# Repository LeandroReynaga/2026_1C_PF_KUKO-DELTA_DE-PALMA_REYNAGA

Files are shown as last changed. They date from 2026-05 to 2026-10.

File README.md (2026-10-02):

<div align="center">
Banner_KUKO_Delta_Carbon
<br>

# KUKO DELTA CARBON

### Robot delta de 3 GDL con visión artificial para clasificación de piezas sobre cinta en movimiento

<br>













<br>

Universidad Nacional de Lomas de Zamora — Facultad de Ingeniería

**Universidad Nacional de Lomas de Zamora · Facultad de Ingeniería**<br>
**Ingeniería Mecatrónica**

</div>

---

## Ficha del proyecto

| | |
| :--- | :--- |
| **Proyecto** | KUKO Delta Carbon |
| **Tipo** | Proyecto Final (PF) |
| **Año / Período** | 2026 — 1.er Cuatrimestre |
| **Carrera** | Ingeniería Mecatrónica |
| **Autores** | **DE PALMA, Marcos Agustín** · **REYNAGA RÍOS, Leandro Joel**  |
| **Institución** | Facultad de Ingeniería — UNLZ |
| **Estado** | 🟢 Prototipo funcional |
| **Repositorio** | `2026_1C_PF_KUKO-DELTA_DE-PALMA_REYNAGA` |

---

<p align="center">
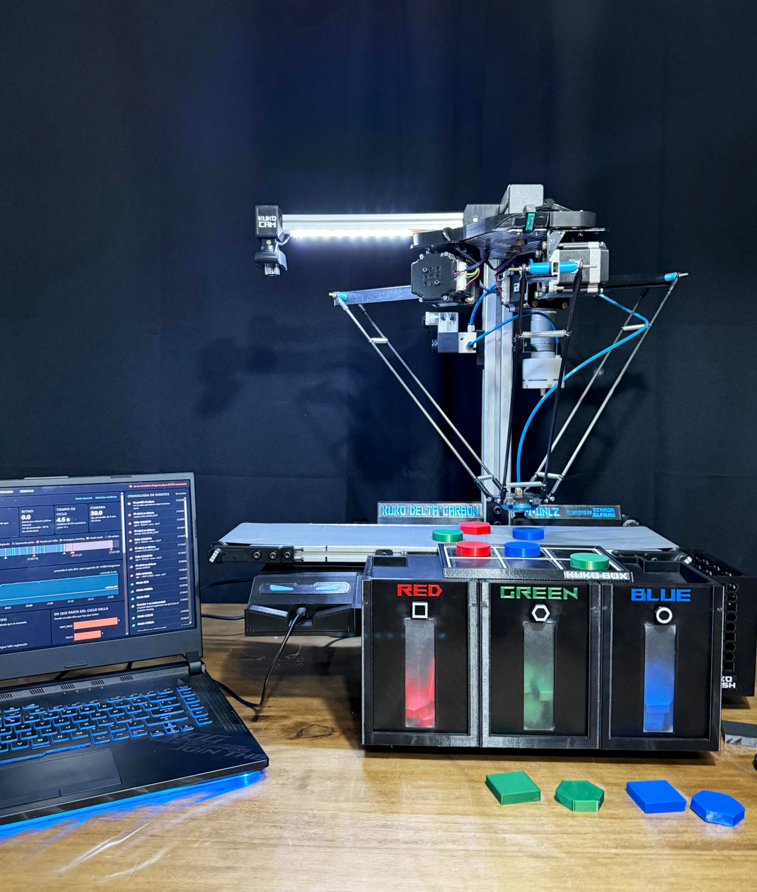
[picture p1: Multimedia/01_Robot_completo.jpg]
KUKO Delta Carbon
  
  <br>
  <em>Imagen 1: KUKO Delta Carbon</em>
</p>

---

## 📑 Índice

|  #  | Sección | Contenido |
| :-: | :--- | :--- |
|  1  | [Introducción y objetivos](#introduccion) | Contexto, problema y objetivos |
|  2  | [Brief](#brief) | Pitch, solución, alcance y estado |
|  3  | [Multimedia](#multimedia) | GIF, videos y visor 3D con AR |
|  4  | [Descripción técnica](#descripcion-tecnica) | Cómo funciona por dentro |
|  5  | [Instrucciones de uso](#uso) | Puesta en marcha reproducible |
|  6  | [Desarrollo del proyecto](#desarrollo) | Diagrama de Gantt |
|  7  | [Autores](#autores) | Contacto |

---

## 1 · Introducción y objetivos

### Contexto

**KUKO Delta Carbon** es una celda de clasificación, de escala didáctica pero con criterios
industriales, construida íntegramente por los autores: mecánica, electrónica, firmware, visión
artificial e interfaz de operación.

### Problema a resolver

Tomar piezas **en movimiento** sobre una cinta transportadora y depositarlas en el destino que les
corresponde, sin detener la cinta, es un problema de sincronización. Resolverlo exige medir la latencia del sistema
de visión, predecir la posición futura de la pieza y planificar la intercepción, todo con hardware
de bajo costo y sobre motores paso a paso.

### Objetivo general

> Diseñar, construir y poner en marcha una celda robótica de clasificación automática basada en un
> robot delta de 3 grados de libertad, capaz de detectar piezas por **color** y **forma** mediante
> visión artificial, interceptarlas sobre una cinta en movimiento y depositarlas en su destino,
> supervisada desde una interfaz de operación propia.

---

## 2 · Brief

> **KUKO Delta Carbon** es una celda robótica *pick & place* que clasifica piezas por color y forma
> sobre una cinta en movimiento, pensada para tareas de selección repetitivas.

Este proyecto **KUKO Delta Carbon** (Proyecto Final, **2026 · 1.er Cuatrimestre**) resuelve la
**clasificación manual de piezas en línea de producción** mediante un **robot delta de 3 GDL con
visión artificial que intercepta las piezas sin detener la cinta**.
Permite **clasificar
por color, por forma o armar una caja de 6 posiciones**, con una interfaz que muestra en vivo el
estado de cada componente, la producción acumulada y la disponibilidad de la celda.

Se implementa con **ESP32 + C++ (PlatformIO)** para el control en tiempo real y **Python + OpenCV +
NiceGUI** para la visión y la operación, y se valida con **98 pruebas automáticas** que verifican
tanto el protocolo de comunicación como la matemática del movimiento.

<table>
<tr><td width="52%" valign="top">

**Para lograrlo:**

- 👁️ **Detecta** piezas por color (rojo · verde · azul) y forma (cuadrado · hexágono · círculo)
- 🎯 **Intercepta** la pieza en movimiento
- 🗑️ **Clasifica** en 3 tachos, por color o por forma
- 📦 **Modo Box:** llena una caja de 6 celdas con una disposición de colores configurable
- 🛡️ **Supervisa colisiones** con encoders magnéticos y se recupera sola rehomeando
- 🧑‍🏫 **Modo Teach:** el operador mueve el brazo a mano, graba secuencias y las reproduce
- 📊 **Mide su propia producción:** piezas, ritmo, fallos y disponibilidad
- ⚙️ **62 parámetros ajustables**, sin recompilar y persistidos en la placa

</td><td width="48%" valign="top">

```
      Cámara USB 720p
             ↓  OpenCV (HSV + contornos)
  Color · Forma · Posición Y
             ↓  Serie 115200 8N1
  ESP32 — planificación e intercepción
             ↓  Cinemática inversa delta
  3 × NEMA 23 (10.000 µpasos/vuelta)
             ↓  Ventosa de vacío
  Pieza depositada en su destino
             ↑
  3 × AS5600 → supervisión de colisión
```

</td></tr>
</table>

### Alcance

<table>
<tr>
<th width="50%">✅ Incluye</th>
<th width="50%">🚫 No incluye</th>
</tr>
<tr><td valign="top">

- Robot delta de 3 GDL con ventosa de vacío
- Cinta transportadora con velocidad regulada por PWM
- Visión artificial por color y forma, con seguimiento
- Intercepción de piezas en movimiento
- Detección de colisiones y recuperación automática
- Registro de fallos e indicadores de producción
- Interfaz web de operación, proceso y servicio
- Modo Teach con grabación y reproducción de rutas
- Movimiento lineal (movL) en el espacio cartesiano

</td><td valign="top">

- Alimentador automático de piezas
- Vacuostato (confirmación física del vacío)
- Vision Artificial con Redes neuronales

</td></tr>
</table>

### Estado del proyecto

| Aspecto | Estado |
| :--- | :--- |
| **Madurez** | ✅ Prototipo funcional |
| **Ciclo completo** | ✅ Homing → detección → intercepción → agarre → clasificación → retorno |
| **Modos operativos** | ✅ Color · Forma · Box · Teach |
| **Seguridad** | ✅ Supervisión de colisión activa, con recuperación automática |
| **Interfaz** | ✅ 6 pestañas operativas (Operación, Teach, Rendimiento, Visión, Proceso, Servicio) |

---

## 3 · Multimedia

<p align="center">
  <a href="https://leandroreynaga.github.io/2026_1C_PF_KUKO-DELTA_DE-PALMA_REYNAGA/Multimedia/KUKO_AR/">
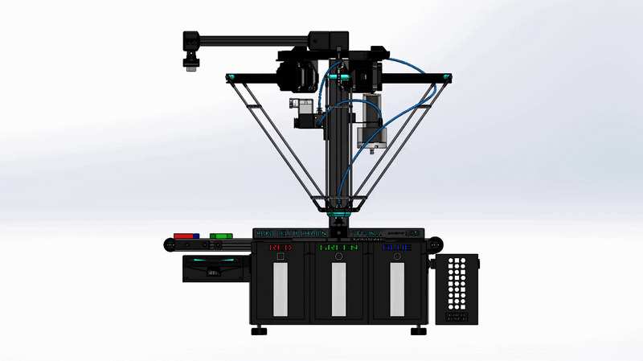
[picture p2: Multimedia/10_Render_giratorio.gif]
Render giratorio: clic para ver el robot en 3D y realidad aumentada
    
  </a>
  <br>
  <em>Figura 1: Render giratorio del modelo 3D</em>
</p>

<p align="center">
  <a href="https://leandroreynaga.github.io/2026_1C_PF_KUKO-DELTA_DE-PALMA_REYNAGA/Multimedia/KUKO_AR/"><b>🔍 Ver en 3D y Realidad Aumentada</b></a>
</p>
<p align="center">
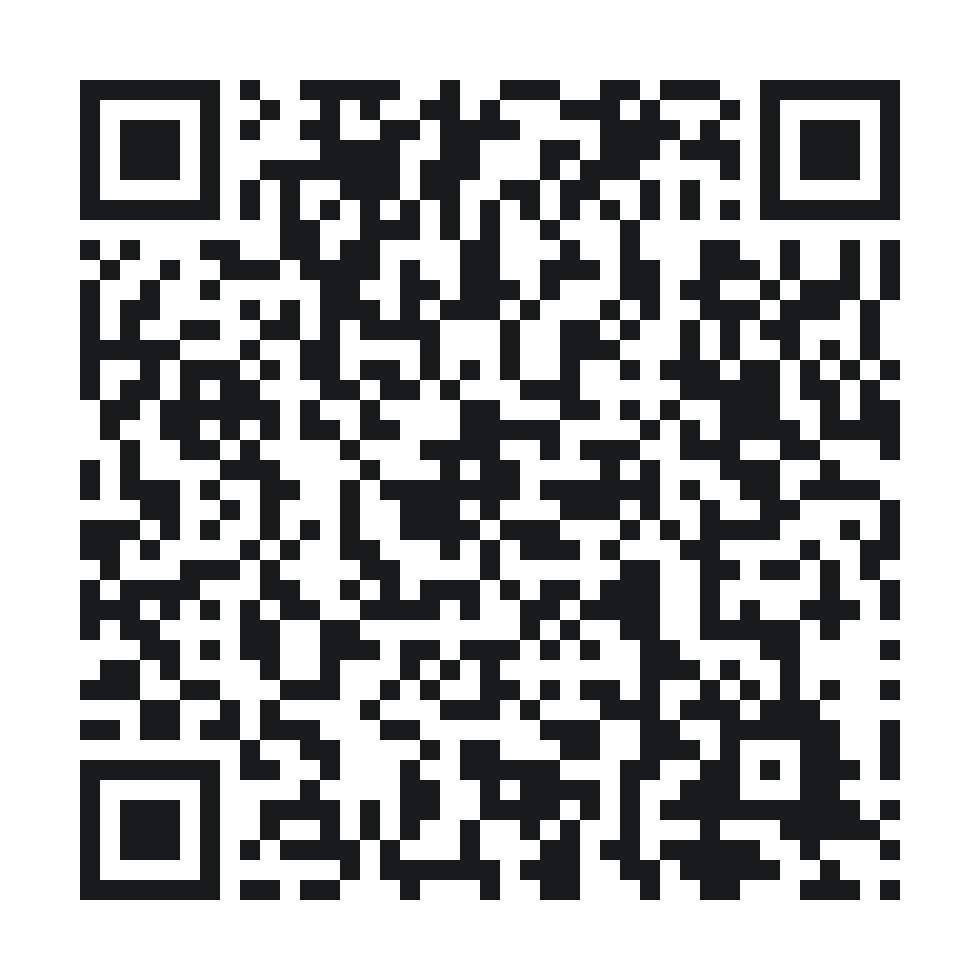
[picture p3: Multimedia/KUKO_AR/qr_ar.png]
Código QR para ver el robot en realidad aumentada
  
  <br>
  <em>Enlace 1: Haz clic en el render o escanea el QR con el celular para ver el robot en 3D y en realidad aumentada.</em>
</p>

<p align="center">
  Clasificación por color
  <br>
  <em>Figura 2: Clasificación por color</em>
</p>

<p align="center">
  Clasificación por forma
  <br>
  <em>Figura 3: Clasificación por forma</em>
</p>

<p align="center">
  Modo Box
  <br>
  <em>Figura 4: Modo Box</em>
</p>

<p align="center">
  Modo Teach
  <br>
  <em>Figura 5: Modo Teach</em>
</p>

<p align="center">
  <a href="https://youtube.com/playlist?list=PLV_DUMoOxinw&amp;si=bVj7ZXU2DtyZ1oJc">
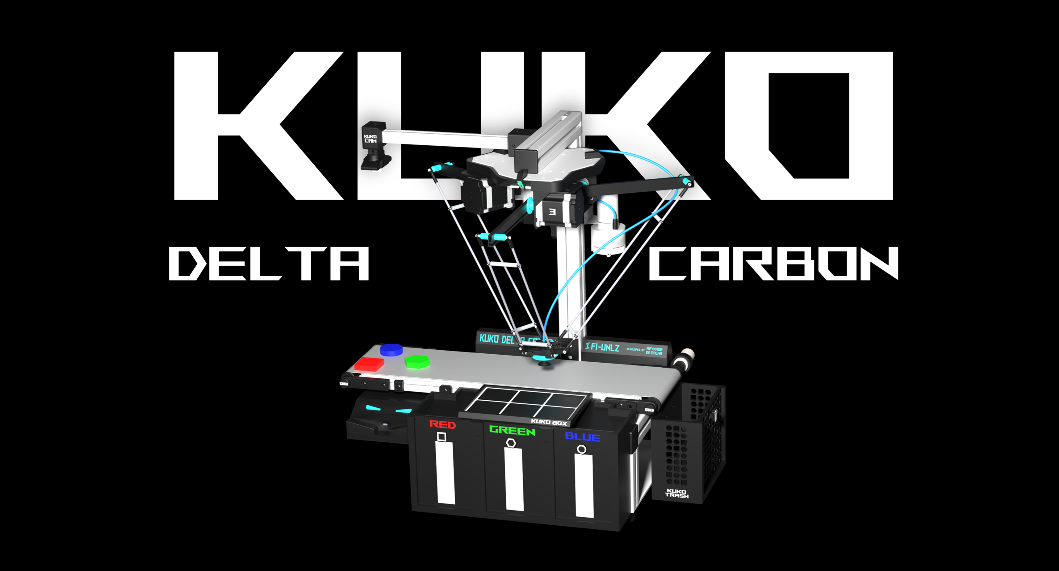
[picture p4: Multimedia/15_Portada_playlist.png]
Playlist de videos del KUKO Delta Carbon
    
  </a>
</p>
<p align="center">
  <em>Enlace 2: Haz clic en la imagen para ver la playlist con los videos de los modos.</em>
</p>

<p align="center">
  <a href="https://drive.google.com/drive/folders/15TBgdvEbJJ4iwdDsnXzpPRDG5-t90HLm?usp=drive_link">
    Google Drive_Logo

  </a>
</p>
<p align="center">
  <em>Enlace 3: Haz clic en la imagen para descargar el modelo 3D y los videos.</em>
</p>

---

## 4 · Descripción técnica

El sistema se reparte responsabilidades: el ESP32 hace
lo que **no puede esperar** (generar pasos, leer encoders, decidir cuándo bajar el brazo) y la PC hace
lo que **necesita memoria y potencia** (procesar imagen, dibujar, recordar sucesos).

### 4.1 · Ciclo de clasificación

```mermaid
stateDiagram-v2
    direction LR
    [*] --> HOMING
    HOMING --> WAIT_PIECE : finales de carrera + calibración de encoders
    WAIT_PIECE --> PICK_APPROACH : llega una pieza alcanzable
    PICK_APPROACH --> PICK_DESCEND : espera sobre el punto de encuentro
    PICK_DESCEND --> PICK_LIFT : baja a favor de la cinta y toma la pieza
    PICK_LIFT --> GO_BIN : modo Color / Forma
    PICK_LIFT --> BOX_TRANSIT : modo Box
    GO_BIN --> BIN_SETTLE
    BIN_SETTLE --> RELEASE_WAIT
    RELEASE_WAIT --> WAIT_PIECE
    BOX_TRANSIT --> BOX_APPROACH
    BOX_APPROACH --> BOX_DESCEND
    BOX_DESCEND --> BOX_LIFT
    BOX_LIFT --> WAIT_PIECE
    WAIT_PIECE --> GO_HOME_IDLE : sin piezas en cola
    GO_HOME_IDLE --> WAIT_PIECE
    HOMING --> COLLISION_STOP : cualquier estado puede caer acá
    COLLISION_STOP --> HOMING : recalibra conservando la cola
    WAIT_PIECE --> TEACH : pedido del operador (J1)
    TEACH --> WAIT_PIECE
```

<p align="center"><em>Figura 6: Máquina de estados del ciclo de clasificación</em></p>

### 4.2 · Modos de clasificación

| Modo | Comando | Qué hace |
| :--- | :-----: | :--- |
| **Color** | `C` | Tacho 1 rojo · Tacho 2 verde · Tacho 3 azul |
| **Forma** | `F` | Tacho 1 cuadrado · Tacho 2 hexágono · Tacho 3 círculo |
| **Box** | `A` | Llena una caja de 6 celdas (2 filas × 3 columnas) con una disposición de colores configurable; máximo 3 piezas por color. El resto de las piezas siguen de largo |

### 4.3 · Visión artificial

La detección corre en la PC sobre **OpenCV**, con procesamiento clásico (sin redes neuronales): es
determinístico, se calibra a mano.

**La `X` de la pieza no viaja por el enlace.** Como el aviso se emite exactamente en el cruce de la
 línea de detección, la `X` es siempre la misma y es conocida por las dos partes. Solo viajan
 `Y`, color y forma — tres campos, dos comas, una línea.

### 4.4 · Cinemática

`DeltaKinematics` es un espacio de nombres puramente matemático —sin entrada/salida ni llamadas a
motores— que resuelve la **cinemática inversa** del delta. La **cinemática directa** vive del lado de
Python (`cinematica.py`), y la necesita para dibujar el brazo en pantalla.

### 4.5 · Generación de pasos y perfiles de movimiento

Cada eje se maneja con un **timer de hardware dedicado** del ESP32 y una rampa trapezoidal calculada
con el **algoritmo de Austin (2004)**.

**Coordinación multi-eje.** `Motors::moveSynchronized` escala velocidad y aceleración de cada eje en
proporción a su recorrido, de modo que los tres motores **arrancan y llegan juntos** aunque recorran
distancias distintas.

### 4.6 · Supervisión de colisiones

**No es control de posición** — la posición sigue siendo lazo abierto por micropasos. Es un
 **detector de discrepancia**: en cada vuelta del loop compara el ángulo medido contra el que dicen
 los pasos emitidos, y si la diferencia supera el umbral **y se sostiene** durante un tiempo de
 confirmación, declara colisión.

**El umbral no es fijo:**

```
umbral_efectivo = UMBRAL_DEG + MARGEN_VELOCIDAD_MS × velocidad
```

**Reacción ante colisión:** frena los 3 ejes → suelta la pieza → espera 3 s → rehomea conservando la
cola de piezas. Tras 3 colisiones seguidas, pasa a `ERROR`.

### 4.7 · Modo Teach

Un modo aparte del ciclo de clasificación: el operador maneja el brazo a mano desde la interfaz, graba
secuencias y las reproduce. Incluye verificación por etapas.

### 4.8 · Interfaz de operación

Aplicación web local hecha con **NiceGUI**, en un solo proceso y tres hilos: visión, enlace serie y
servidor web. Sirve para controlar el proceso, modificar variables, enterarse de errores y verificar componentes. 

---

## 5 · Instrucciones de uso

### 5.1 · Requisitos previos

| Categoría | Requisito |
| :--- | :--- |
| **Sistema operativo** | Windows 10/11  |
| **Firmware** | [PlatformIO](https://platformio.org/) (CLI `pio` o la extensión de VS Code) |
| **PC** | Python **3.13** o superior |
| **Driver USB** | CP2102 — incluido en [`Código/Driver_USB_CP2102/`](C%C3%B3digo/Driver_USB_CP2102/) |
| **Hardware** | Robot Kuko Delta Carbon |

### 5.2 · Instalación

**a) Clonar el repositorio**

```bash
git clone https://github.com/<usuario>/2026_1C_PF_KUKO-DELTA_DE-PALMA_REYNAGA.git
cd "2026_1C_PF_KUKO-DELTA_DE-PALMA_REYNAGA/Código/KUKO_DELTA_CARBON"
```

**b) Instalar el driver USB** (solo la primera vez)

Ejecutar el instalador de `Código/Driver_USB_CP2102/CP210x_Universal_Windows_Driver/` según la
arquitectura de la PC. Sin esto, el ESP32 no aparece como puerto COM.

**c) Compilar y cargar el firmware**

```bash
pio run                        # compila el entorno "main"
pio run -e main -t upload      # flashea la placa
pio device monitor             # monitor serie a 115200 baudios
```

<details>
<summary><b>Entornos de compilación disponibles</b></summary>

<br>

La carpeta `pruebas/` guarda sketches históricos (`.bak`) de motores, encoders y cinemática, además de
`test.cpp`, que es lo que compila el entorno `test`. Los `.bak` no forman parte de ningún build, pero
sirven de referencia al depurar un subsistema por separado.

</details>

**d) Preparar la aplicación de PC**

```bash
python -m venv pc/.venv
pc\.venv\Scripts\pip install -r pc/requirements.txt
```

### 5.3 · Puesta en marcha

```bash
pc\.venv\Scripts\python pc/kuko_app.py
```

Opciones útiles:

```bash
pc\.venv\Scripts\python pc/kuko_app.py --puerto COM5      # forzar el puerto serie
pc\.venv\Scripts\python pc/kuko_app.py --sin-vision       # trabajar en la interfaz sin cámara
pc\.venv\Scripts\python pc/kuko_app.py --sin-navegador    # no abrir el navegador solo
```

La interfaz queda en **`http://localhost:8080`**.

---

## 6 · Desarrollo del proyecto

El proyecto se construyó **de abajo hacia arriba**: primero cada subsistema por separado y verificado
en aislamiento, después la integración. Cada capa nueva se apoyó en una que ya estaba medida.

### Diagrama de Gantt

Cronograma del proyecto de marzo a octubre de 2026, en seis etapas. El detalle de cada tarea está en el
[Diagrama de Gantt final](Documentaci%C3%B3n/Diagrama%20de%20Gantt/Diagrama_de_Gantt_final.pdf).

<p align="center">
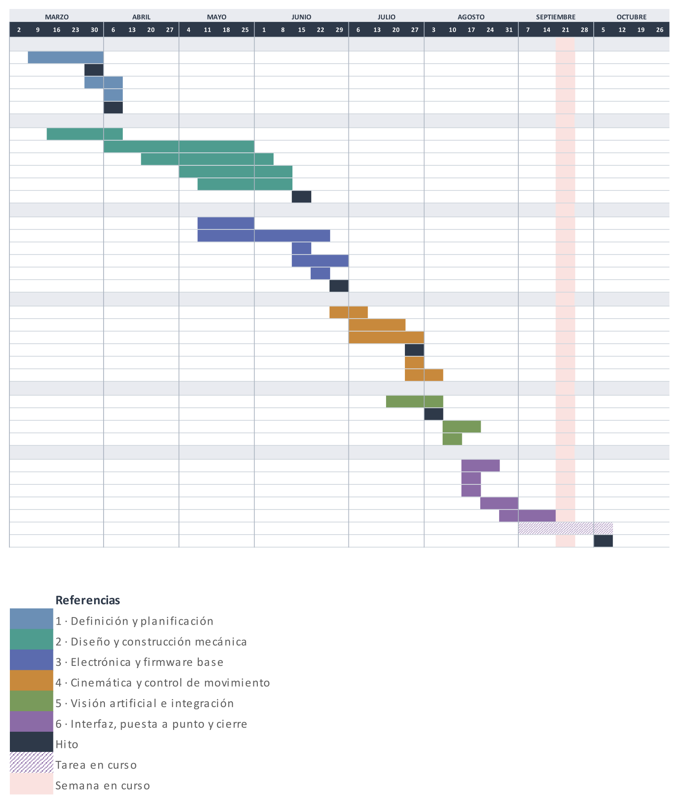
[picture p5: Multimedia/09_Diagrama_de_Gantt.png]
Diagrama de Gantt final
  
  <br>
  <em>Figura 7: Diagrama de Gantt final</em>
</p>

---

## 7 · Autores

<table align="center">
<tr><td width="50%" align="center">

### DE PALMA<br>Marcos Agustín

Ingeniería Mecatrónica — FI-UNLZ

📧 <marcosdepalma03@gmail.com>

💻 GitHub [@MarcosDePalma](https://github.com/MarcosDePalma)

</td><td width="50%" align="center">

### REYNAGA RÍOS<br>Leandro Joel

Ingeniería Mecatrónica — FI-UNLZ

📧 <leandro_05_01@hotmail.com>

💻 GitHub [@LeandroReynaga](https://github.com/LeandroReynaga)

</td></tr>
</table>

---

<div align="center">

**KUKO DELTA CARBON**

**Facultad de Ingeniería — Universidad Nacional de Lomas de Zamora**<br>
Proyecto Final · 2026 · 1.er Cuatrimestre

</div>

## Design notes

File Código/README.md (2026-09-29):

# Código

Código fuente del **KUKO Delta Carbon** y el driver USB para conectar la placa a la PC.

El sistema son dos partes que se comunican por puerto serie: el **firmware** del ESP32
(PlatformIO / Arduino) y la **aplicación de PC** (Python).

## Contenido

| Carpeta | Contenido |
|---|---|
| [`KUKO_DELTA_CARBON/`](KUKO_DELTA_CARBON/) | Proyecto completo: firmware y aplicación de PC. |
| [`Driver_USB_CP2102/`](Driver_USB_CP2102/) | Driver de Windows para el conversor USB-serie CP2102 de la NodeMCU-32S, comprimido y descomprimido. |

## KUKO_DELTA_CARBON

| Ubicación | Contenido |
|---|---|
| `platformio.ini` | Configuración de PlatformIO: entorno `main` (firmware) y `test` (pruebas de placa). |
| `include/Pinout.h` | Asignación de pines del ESP32. Es el único lugar donde se definen. |
| `src/` | Firmware: máquina de estados, generación de pasos, cinemática, trayectorias, encoders, finales de carrera, neumática y cinta. |
| `pc/` | Aplicación de PC: enlace serie, visión, interfaz, teach y rendimiento. |
| `pc/PROTOCOLO.md` | Protocolo de comunicación serie entre la PC y el ESP32. |
| `pc/tests/` | Pruebas de la aplicación de PC. |
| `vision_python/` | Módulos de visión calibrados: cámara, detección por color y forma, seguimiento y conversión a coordenadas del robot. |
| `pruebas/` | Programas de prueba de la puesta en marcha de la placa. |
| `estructura.txt` | Estructura del proyecto, archivo por archivo. |
| `CLAUDE.md` | Guía del proyecto para Claude Code. |

**Volumen:** ~11.400 líneas de firmware (C++) y ~19.600 de aplicación de PC (Python).

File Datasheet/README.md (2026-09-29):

# Datasheets

Hojas de datos de los componentes principales del KUKO Delta Carbon.

| Componente | Archivo | Dato que interesa |
| :--- | :--- | :--- |
| ESP32 NodeMCU-32S | `esp32_nodemcu_32s.pdf` | Pines con ADC, canales PWM, timers de hardware |
| Driver DM556 | `dm556.pdf` | Tabla de microstepping y de corriente (DIP switches) |
| Motor NEMA 23 | `nema23.pdf` | Par, corriente por fase, inercia del rotor |
| Encoder AS5600 | `as5600.pdf` | Salida analógica, resolución, alimentación ratiométrica |
| Bomba de vacío | `microbomba.pdf` | Consumo y caudal |
| Electroválvula | `electrovalvula.pdf` | Alimentación, acción directa, rango de presiones|
| Cámara USB | `camara_usb.pdf` | Resolución, modos de captura |
| Driver DRV8833 | `drv8833.pdf` | Pinout, corriente máxima |
| Motorreductor 60RPM | `motorreductor.pdf` | Torque a tensión nominal, rpm |
| Switch Final de Carrera | `final_de_carrera.pdf` | Dimensiones, NO y NC|

---

> **Los aspectos más importantes**

> - La **placa ESP32** debe tener suficiente capacidad de procesamiento y cantidad de pines para todos los componentes del robot.
> - La selección del modelo de **motores paso a paso** es fundamental para garantizar **torque sostenido a altas RPM** ya que una caída
>   del torque genera pérdida de pasos.
> - El **circuito neumático** debe ser capaz de generar vacío y liberar el sistema **a alta velocidad**.
> - La **cámara** debe tener suficiente resolución y contraste.
> - La **cinta transportadora** no debe trabarse durante el funcionamiento.

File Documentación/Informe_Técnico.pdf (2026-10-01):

### Universidad Nacional de Lomas de Zamora

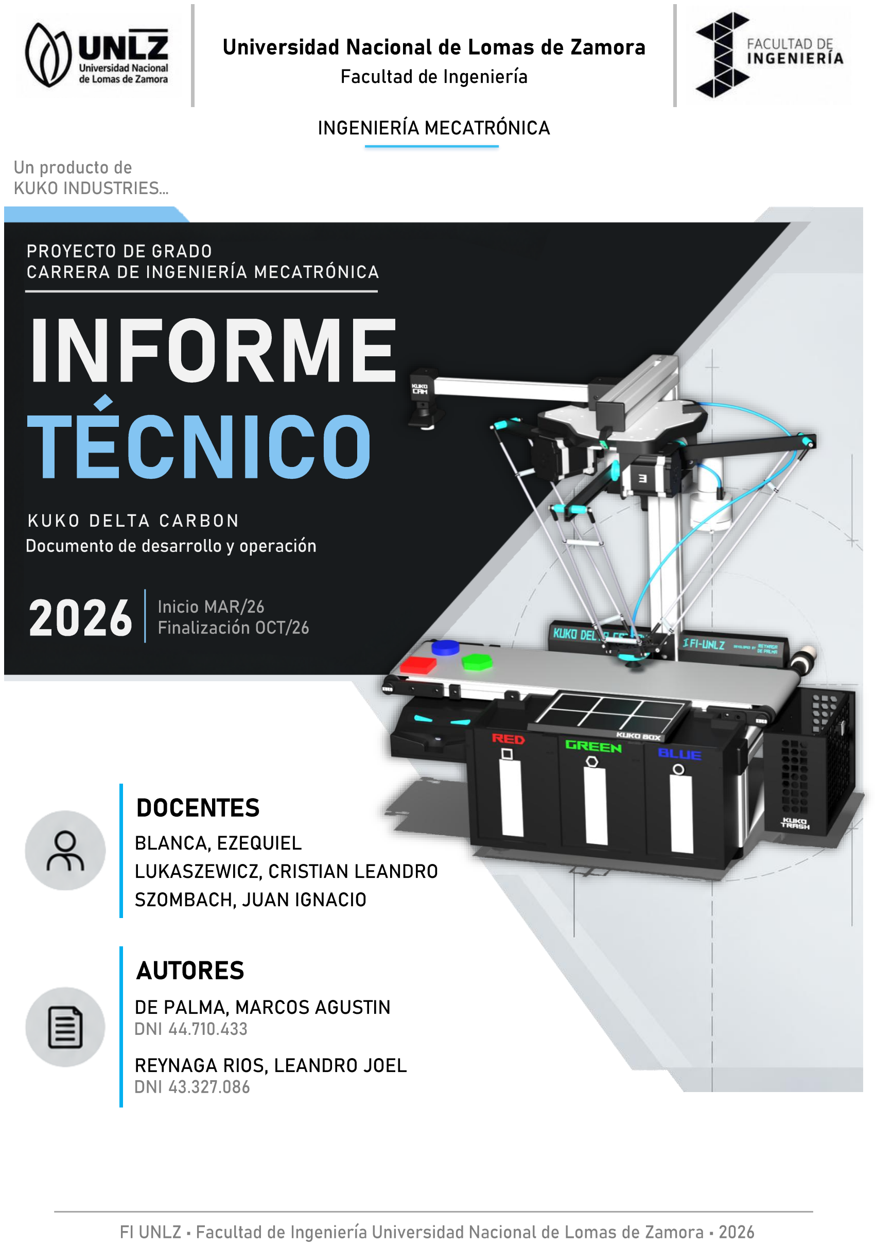
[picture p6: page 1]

Facultad de Ingeniería

INGENIERÍA MECATR ÓNICA

Un producto de
KUKO INDUSTRIES …

z

## DOCENTES

BLANCA, EZEQUIEL
LUKASZEWICZ, CRISTIAN LEANDRO SZOMBACH, JUAN IGNACIO

## AUTORES

DE PALMA, MARCOS AGUSTIN
DNI 44.710.433

REYNAGA RIOS, LEANDRO JOEL DNI 43.327.086

PROYECTO DE | GRADO
CARRERA DE | INGENIERÍA MECATRÓNICA

# INFORME TÉCNICO

KUKO DELTA CARBON
Documento de desarrollo y operación

2026 Inicio MAR/26
Finalización OCT/26

FI UNLZ • Facultad de Ingeniería Universidad Nacional de Lomas de Zamora • 2026

Índice

## Índice

Índice

Índice

11.1. Arquitectura de la aplicación | 61
11.2. Pestaña de Operación | 61
11.3. Pestaña de Teach | 62
11.4. Pestaña de Rendimiento | 63
11.5. Pestaña de Visión | 65
11.6. Pestañas de Proceso y Servicio | 66
12. | PLANIFICACIÓN Y DESARROLLO | | 69
12.1 Diagrama de Gantt inicial | 69
12.2 Diagrama de Gantt final | 69
12.2 Aclaración | 71
12.3 Comparativa | 72
13. | PRUEBAS Y RESULTADOS | | 73
13.1 Pruebas durante el desarrollo | 73
13.2 Resultados de funcionamiento | 73
14. | ANÁLISIS ECONÓMICO | | 74
14.1. Criterios de selección de proveedores | 74
14.2. Listado de materiales y costos | 75
14.3. Desvío presupuestario | 76
15. | CONCLUSIONES | | 77
15.1 Conclusiones generales | 77
15.2. Mejoras futuras | 78
16. | MATERIAL GRÁFICO Y AUDIOVISUAL | | 79
Recorrido del proyecto | 79
Playlist: Videos de los modos | 80
Video modo: Clasificación por color | 80
Video modo: Clasificación por forma | 80
Video modo: Box | 80
Video modo: Teach | 81
Autores del proyecto | 81

Introducción

## 1. INTRODUCCIÓN

### 1.1. Contexto y motivación

Siguiendo la línea de desarrollo del robot KUKO S -300 realizado en la materia Robótica, nos vimos impulsados a crear el KUKO Delta Carbon , un modelo con aplicación industrial. Buscamos crear un sistema de clasificación Pick and Place, compuesto por un robot delta, una cinta transportadora y depósitos fijos, destinado al manejo de piezas livianas en entornos productivos.

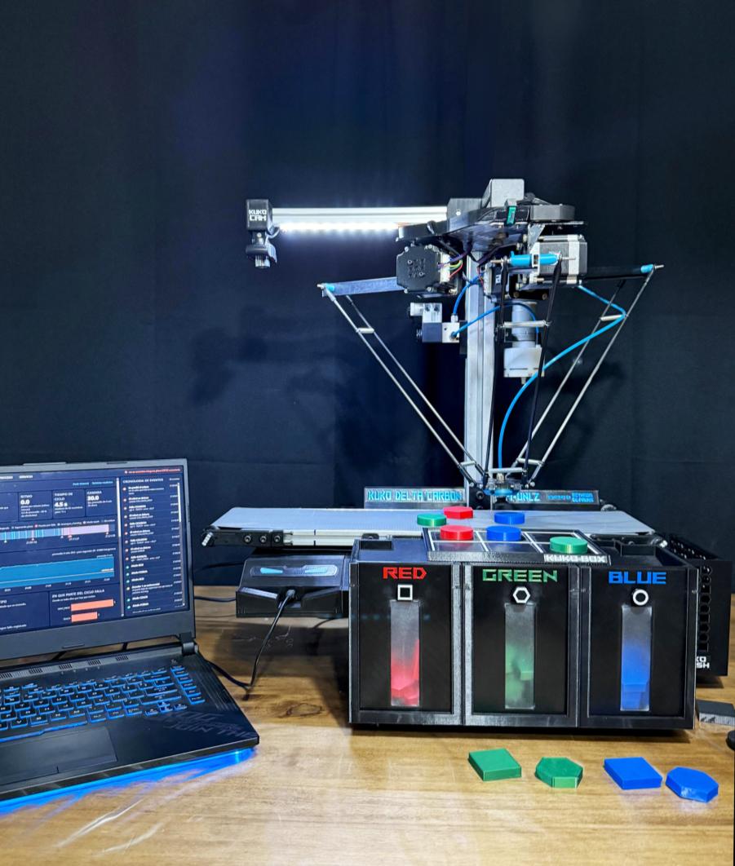
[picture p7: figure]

Imagen 1 – Kuko Delta Carbon

Inicialmente, se planteó el desarrollo de un robot de configuración SCARA de 3 grados de libertad con gripper mecánico, aprovechando el conocimiento adquirido con el S -300, un robot de 2 grados de libertad . Sin embargo, al analizar los requerimientos de velocidad y productividad del sistema, se concluyó que dicha configuración no resultaba adecuada para cumplir con las exigencias planteadas.

En búsqueda de velocidad y precisión, los robots paralelos del tipo DELTA destacan por sobre el resto, y esto nos motivó a optar por esta configuración. Este tipo de robot es ampliamente utilizado
en la industria para tareas de clasificación, empaquetado y transferencia de productos , por lo que e l sistema incorporó un gripper neumático basado en ventosa, seleccionado por su rapidez de actuación y confiabilidad en la manipulación de piezas, en comparación con sistemas de agarre mecánico que pueden presentar limitaciones en este tipo de aplicaciones .

Introducción

Nuestro prototipo buscó dar a conocer las capacidades de un robot de configuración Delta, proponiendo una alternativa a las configuraciones robóticas tradicionales, donde predominan los robots antropomórficos o de tipo SCARA. De esta manera, el proyecto buscó ser una propuesta innovadora, orientada a ampliar el enfoque, explorando nuevas configuraciones robóticas.

En este contexto, el presente documento tiene como propósito documentar el proceso de diseño, construcción e implementación del prototipo, desarrollado en el marco de l Proyecto Final en Ingeniería Mecatrónica de la Facultad de Ingeniería de la Universidad Nacional de Lomas de Zamora.

En base al robot realizado , se aborda el análisis cinemático del mecanismo, el diseño mecánico y
electrónico, el firmware de control, el sistema de visión artificial y la interfaz de operación | .

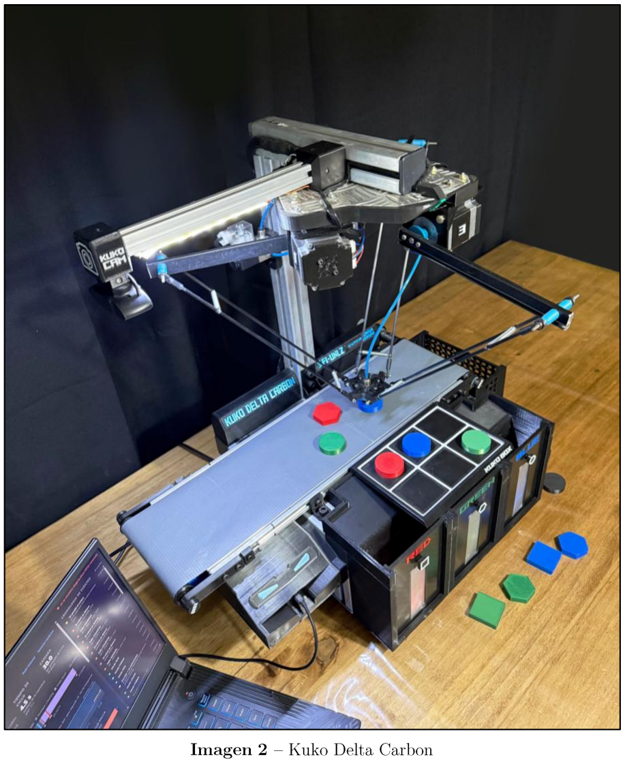
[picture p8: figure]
Imagen 2 – Kuko Delta Carbon

La marca KUKO INDUSTRIES | es ficticia y no corresponde a ninguna empresa real. | E s una
denominación adoptada por los autores para identificar la línea de proyectos que incluye | :
- El KUKO S -300
- E l presente KUKO Delta Carbon.

Objetivos

## 2. OBJETIVOS

### 2.1 Objetivo general

Diseñar, construir e implementar un prototipo funcional de un sistema automatizado de clasificación de piezas del tipo Pick and Place, basado en un robot paralelo de configuración delta de
tres grados de libertad, con capacidad de detectar e interceptar piezas en movimiento sobre una cinta transportadora mediante visión artificial, y clasificarlas en los depósitos correspondientes mediante un sistema de agarre neumático por ventosa.

### 2.2. Objetivos específicos

Para alcanzar el objetivo general se plantearon los siguientes objetivos específicos:

1. Diseñar y construir la estructura mecánica del robot delta y | de la cinta transportadora,
definiendo los parámetros geométricos del mecanismo.
2. Desarrollar el modelo cinemático directo e inverso del robot.
3. Diseñar e implementar el sistema electrónico de potencia, control y sensado, incorporando realimentación de posición mediante encoders magnéticos.
4. Desarrollar el firmware de control en tiempo real encargado de la generación de trayectorias y del movimiento coordinado de los tres ejes.
5. Implementar un sistema de visión artificial capaz de determinar la posición de las piezas sobre la cinta y de clasificarlas según su color y su forma.
6. Desarrollar la estrategia de intercepción que permita tomar las piezas en movimiento mediante un sistema de agarre neumático por ventosa, sin detener la cinta transportadora.
7. Incorporar mecanismos de supervisión de fallos y recuperación automática que aseguren una operación robusta del sistema.
8. Desarrollar una interfaz de operación que permita controlar el proceso, supervisar el estado de los componentes y ajustar parámetros del sistema.
9. Validar el funcionamiento del prototipo mediante ensayos sobre el sistema construido.

Marco Teórico

## 3. MARCO TE Ó RICO

### 3.1. Robots manipuladores

Un robot manipulador es un sistema mecánico articulado, compuesto por un conjunto de eslabones rígidos unidos entre sí mediante articulaciones, algunas de ellas motorizadas, capaz de posicionar y orientar un elemento terminal , el efector, dentro de un volumen del espacio. La forma en que esos eslabones se conectan entre sí define la primera y más importante clasificación de los robots manipuladores: según se trate de una cadena cinemática abierta o cerrada (Tsai, 1999).

### 3.1.1 Cadena cinemática abierta y cerrada

Un robot de cadena cinemática abierta | , también llamado robot serie | , tiene sus eslabones
dispuestos uno a continuación del otro, formando una única secuencia que va desde la base fija hasta
el efector final, de manera análoga al brazo humano: hombro, codo, muñeca y mano en fila. Cada articulación soporta, además de su prop io peso, el de todos los eslabones y actuadores que la siguen en la cadena, lo que limita la aceleración máxima alcanzable y exige motores de mayor potencia a medida que se avanza hacia la base.

Un robot de cadena cinemática cerrada , o robot paralelo , conecta el efector a la base mediante dos o más cadenas cinemáticas que actúan de manera simultánea, formando uno o varios lazos cerrados. Es la misma idea que varias resistencias en paralelo en un circuito eléctrico , existen múltiples caminos entre los mismos dos puntos. En esta arquitectura, los actuadores quedan fijos sobre la base y solo desplazan eslabones livianos, sin cargar con el peso de otros motores, lo que le permite alcanzar aceleraciones muy superiores a las de un robot serie de potencia equivalente (Merlet, 2006).

Esta distinción no es meramente descriptiva , determina buena parte de las ventajas y desventajas
que se des criben más adelante . La búsqueda de | velocidad y precisión | motivó la elección de una
arquitectura paralela para este proyecto.

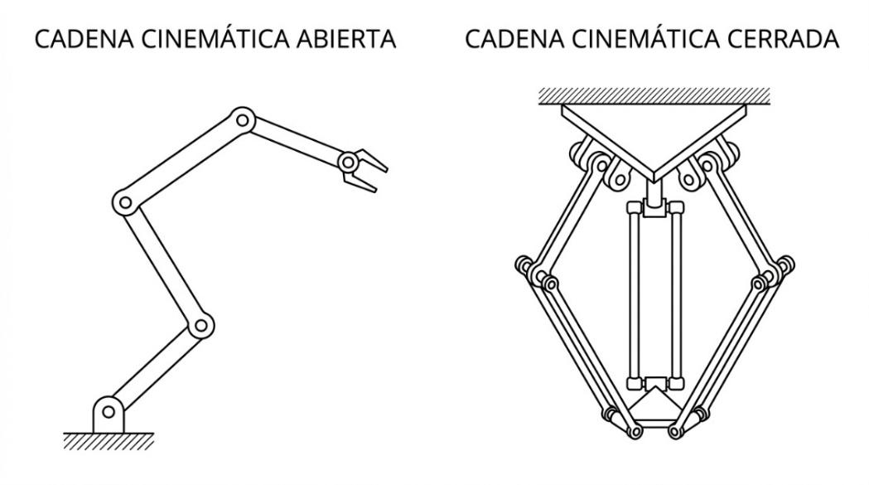
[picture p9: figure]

Figura 1 – Cadena cinemática abierta y cerrada.

Marco Teórico

3.1. 2 Grados de libertad
Los grados de libertad (GDL) de un mecanismo son la cantidad de parámetros independientes necesarios para determinar por completo la posición y orientación de su elemento terminal en el espacio. Un cuerpo rígido libre en el espacio tridimensional posee 6 G DL: 3 de traslación (a lo largo de los ejes X, Y, Z) y 3 de rotación (alrededor de esos mismos ejes). Un robot manipulador restringe esa libertad mediante sus articulaciones, de modo que sus GDL quedan determinados por la cantidad y el tipo de articulacion es que lo componen.

En un robot de cadena abierta, el número de GDL coincide, en general, con el número de articulaciones motorizadas: cada actuador controla un grado de libertad independiente. En un robot de cadena cerrada esa correspondencia no es directa, porque los lazos cerrados introducen restricciones adicionales entre los eslabones. El cálculo formal de la movilidad en estos mecanismos se resuelve mediante el criterio de Grübler -Kutzbach:

M = 6(n − j − 1) +∑fi

j

i=1

donde n es el número de eslabones, j el número de articulaciones y ∑ fi

j
i=1

los grados de libertad

### 3.1.3 E spacio de trabajo

El espacio de trabajo (o volumen de trabajo) de un manipulador es el conjunto de todas las posiciones que su efector final puede alcanzar, dados los límites físicos de sus articulaciones y las longitudes de sus eslabones. Determinar el espacio de trabajo e s un paso obligado en el diseño de cualquier manipulador, porque de él depende si el robot puede cumplir con la tarea para la que fue concebido; en los robots paralelos, además, el volumen de trabajo suele ser más reducido en relación con el tamaño de la e structura que en un robot serie equivalente, y no es necesariamente convexo, algo que se retoma, para el caso concreto del robot delta, en el capítulo dedicado al modelo matemático.

### 3.2. Robots paralelos

### 3.2.1 Ventajas y desventajas frente a los robots serie

Dentro de la clasificación de cadena cinemática cerrada presentada en la sección anterior, los robots paralelos tienen sus ventajas y desventajas particulares frente a los robots serie, y se pueden

Entre las ventajas se destacan: Una mayor rigidez estructural, porque la carga se reparte entre varias cadenas cinemáticas en vez de recaer sobre una única cadena en serie; una mayor relación entre la carga que puede manipular y su propio peso, ya que los actuadores permanecen fijos en la base y la masa en movimiento se reduce considerablemente; una mayor precisión de posicionamiento, porque el error de una cadena no se propaga y amplifica hacia el efector de la misma manera que en un robot serie, donde el error de cada eslabón se suma al de los siguientes; y, sobre todo, la posibilidad de

Marco Teórico

alcanzar velocidades y aceleraciones muy superiores, que es la razón concreta por la que este proyecto adoptó esta arquitectura , sección «Contexto y motivación».

Entre las desventajas se cuentan: Un volumen de trabajo más reducido en relación con el tamaño de la estructura; una cinemática directa considerablemente más compleja de resolver que la inversa; la presencia de singularidades dentro del propio volumen de trabajo, en las que el mecanismo pue de perder rigidez o control; y un diseño mecánico y de montaje más exigente, por la cantidad de articulaciones pasivas y la necesidad de mantener tolerancias ajustadas en varias cadenas a la vez.

Los robots paralelos admiten, a su vez, varias subclasificaciones (Merlet, 2006):

- Según los grados de libertad que ofrecen: R obots paralelos planos, que se mueven dentro de un plano con 2 GDL, y robots paralelos espaciales, con hasta 6 GDL.
- | Según el tipo de articulación: | R obots con actuadores rotacionales, donde los motores
giran, y robots con actuadores prismáticos, donde los actuadores se alargan y acortan.
- | Según la simetría de sus cadenas: | R obots simétricos, en los que todas las cadenas
cinemáticas son idénticas entre sí, y robots asimétricos con cadenas de distinta
- | Según el tipo de movimiento que producen: | R obots de traslación pura, robots que
combinan traslación y rotación, y robots de rotación pura.
El robot delta, que se desarrolla en la sección | “El robot delta ”, dentro de esta clasificación | se
encuentra como: espacial, de actuación rotacional, simétrico, y de traslación pura.

### 3.3. El robot delta

3.3.1. Reseña histórica: | El paralelogramo articulado | por Reymond Clavel
Reymond Clavel, investigador de la Escuela Politécnica Federal de Lausana (EPFL), en Suiza,
es reconocido como el creador del robot delta , desarrolló el concepto a comienzos de la década de 1980
y lo patentó en 1985 (Rey y Clavel, 1999; Clavel, 1990). | Su aporte central no fue la arquitectura
paralela en sí , que ya existía desde décadas antes , sino el uso de un paralelogramo articulado en cada uno de los tres brazos, en lugar de un único eslabón rígido.

Un paralelogramo articulado es un mecanismo de cuatro barras en el que el eslabón de entrada y el eslabón de salida se mantienen siempre paralelos entre sí, sin importar el ángulo en que se encuentre el mecanismo. Al reemplazar cada brazo inferior del robot por un par de varillas paralelas, Clavel logró que la plataforma móvil quedara obligada a mantener siempre la misma orientación que la base fija,
sin depender de ningún control activo para lograrlo , es una restricción puramente geométrica.

La consecuencia de esa restricción es la que distingue al delta de cualquier otro robot paralelo espacial, mientras que un mecanismo paralelo genérico de tres cadenas admitiría tanto traslación como

Marco Teórico

rotación de la plataforma , los tres paralelogramos del delta , al actuar en conjunto , eliminan por completo los grados de libertad de rotación. El robot queda restringido a 3 GDL de traslación pura.

Esta restricción geométrica particular tiene una consecuencia teórica | , el criterio de Grübler -
Kutzbach visto en la sección «Grados de libertad» | , donde se supone que las restricciones de las
articulaciones son independientes entre sí, y en el paralelogramo del delta no lo son, porque el paralelismo de las varillas hace que una misma restricción se imponga más de una vez . El cálculo se desarrolla más adelante, en la sección «Grados de libertad de un Delta ».

Además de resolver el problema de la orientación, esta arquitectura permite que los tres motores del delta pued an permanecer fijos sobre la base , logrando que la masa en movimiento se redu zca al mínimo indispensable: los brazos y la plataforma móvil.

La combinación de baja masa móvil y restricciones geométricas es l a que permite a los robots delta comerciales alcanzar altas aceleraciones, muy por encima de lo que logra un robot serie o incluso otros robots paralelos de la misma familia.

Aplicado el criterio de Grübler -Kutzbach al robot delta construido en este proyecto, el cálculo es

M = 6(n − j − 1) +∑fi

j

i=1

Tabla 1 – Grados de libertad de eslabones y articulaciones.

El mecanismo consta de n = 11 eslabones y j = 15 articulaciones, 3 de revolución con fi = 1, y 12 esféricas con fi = 3, de modo que ∑ fi = 3 ⋅ 1 + 12 ⋅ 3 = 39. Reemplazando en la expresión anterior:

M = 6(11 − 15 − 1) + 39 = −30 + 39 = 9

El resultado no es 3, como cabría esperar, sino 9. La diferencia se explica porque cada una de las seis varillas puede girar libremente alrededor de su propio eje longitudinal sin que ese giro modifique
en absoluto la posición de la plataforma móvil , por ser un paralelogramo articulado .

Se trata de seis movilidades pasivas, que el criterio contabiliza pero que no aportan movimiento útil al efector. Descontadas esas seis, la movilidad efectiva del mecanismo resulta:

Mefectiva = 9 − 6 = 3

Elemento | Cantidad | Elemento | Cantidad
Base fija | 1
Brazos superiores | 3
Brazos inferiores | 6
Gripper | 1
Eslabones totales (n) | 11 | Articulaciones totales (j) | 15
| | Articulaciones rotativas
| | motorizadas | 3
| | Articulaciones de rótula | 12

Marco Teórico

El robot posee, entonces, tres grados de libertad. Estos tres grados son | exclusivamente de
traslación , la plataforma móvil | se mantiene siempre paralela a la base fija. El efector puede así
desplazarse en X, Y y Z dentro de su volumen de trabajo, pero conserva invariable su orientación.

Independientemente del fabricante o la aplicación, un robot delta está compuesto por los siguientes elementos (Clavel, 1990; Merlet, 2006):

- Base fija: E structura, habitualmente de forma triangular, sobre la que se montan los tres actuadores. Permanece inmóvil durante todo el funcionamiento del robot.
- Brazos superiores: E slabón rígido por cada pierna, acoplado directamente al eje de su motor correspondiente, que gira dentro de un plano vertical fijo.
- Brazos inferiores (paralelogramos articulados): P ar de varillas paralelas, unidas en sus extremos mediante articulaciones esféricas (rótulas), que conectan el brazo superior con la plataforma
- Plataforma móvil (o efector): E lemento triangular, de dimensiones mucho menores que la base fija, al que se conectan los tres brazos inferiores y sobre el que se monta la herramienta de
- Articulaciones esféricas (rótulas): A rticulaciones pasivas ubicadas en ambos extremos de cada
- Actuadores: T res, uno por cada pierna, montados sobre la base fija. Pueden ser servomotores eléctricos, motores de corriente continua o, como en el caso de este proyecto, motores paso a
- | Herramienta o efector final: | E l elemento que interactúa con la pieza a manipular, montado
sobre la plataforma móvil. Puede tratarse de una pinza mecánica o, como en este proyecto, una

Algunas variantes industriales del robot delta agregan un cuarto actuador, que transmite un movimiento de rotación a la plataforma móvil; esto le agrega al robot un cuarto grado de libertad de orientación, útil para tareas que requieren orientar la pieza a ntes de depositarla.

### 3.3.3. Aplicaciones industriales

La combinación de alta velocidad, baja masa en movimiento y buena repetibilidad hizo que el robot delta se convirtiera, poco después de su invención, en una de las arquitecturas de referencia para tareas de manipulación repetitiva de alta velocidad. El pri mer robot delta comercial fue el ABB IRB 340 FlexPicker, lanzado a fines de la década de 1990, y hoy es uno de los robots industriales más utilizados en aplicaciones de pick and place .

Entre las aplicaciones industriales más habituales de los robots delta se encuentran:

Marco Teórico

- | Empaquetado de alta velocidad , particularmente en la industria alimenticia | con galletitas,
chocolates o productos de panificación, donde se combinan altas tasas de producción con piezas
- | Clasificación y selección de productos | sobre líneas de producción, según criterios como color,
forma o tamaño. También se pueden implementar códigos de barra o QRs .
- | Ensamblaje de componentes pequeños | en la industria electrónica, donde la precisión y la
- Impresión 3D , donde la arquitectura delta se popularizó como alternativa a las impresoras cartesianas por su capacidad de alcanzar velocidades de impresión mayores.

El proyecto desarrollado en este informe se ubica dentro de la segunda categoría: una celda de clasificación automática que aprovecha la velocidad característica de esta arquitectura para interceptar piezas sin necesidad de detener la cinta transportadora que las transporta.

Descripción General del Proyecto

### 4.1. Metodología de desarrollo

El desarrollo del proyecto se organizó en etapas sucesivas, y a cada una se le dedicó el tiempo necesario para alcanzar un resultado sólido antes de avanzar a la siguiente. El criterio que orientó el trabajo fue primero consolidar cada sistema nuevo, antes de seguir con otra capa de desarrollo, con el fin no necesitar volver atrás, sobre etapas ya concluidas.

El proyecto se estructuró en seis etapas: definición y planificación; diseño y construcción
mecánica; electrónica y firmware base; cinemática y control de movimiento; visión artificial e integración; e interfaz, puesta a punto y cierre. Cada una concluyó c on un hito verificable sobre el equipo real, que sirvió de punto de partida para la siguiente.

### 4.2. Herramientas utilizadas

El diseño mecánico , la geometría del robot, el dimensionamiento de los eslabones y el ensamblaje completo de la estructura se realizó en SolidWorks , que permitió crear y verificar las piezas, además de validar el espacio de trabajo teórico antes de fabricar algún componente.

La fabricación de piezas se realizó mediante impresión 3D .

El diagrama de conexión eléctrica se desarrolló en Fritzing , para representar el cableado físico como un esquemático en donde se vea la conexión de todos los componentes eléctricos.

Del lado del software, se utilizó | Visual Studio Code | como entorno de desarrollo unificado para
las dos partes del sistema: el firmware embebido y la aplicación de PC . Trabajar con un mismo editor simplificó la correlación entre las partes.
El firmware está escrito en C ++ sobre Arduino y compilado con la extensión | PlatformIO para
La interfaz está escrita en Python a partir de NiceGUI . Dentro de ella se visualiza | la cámara

El registro de versiones del proyecto se realizó dentro de un repositorio en GitHub ; lo que permitió tener un control de los cambios a lo largo del proyecto , y avanzar desde distintos dispositivos .

### 4.3. Selección de componentes

La selección de los componentes respondió a las exigencias que fueron planteadas , capacidad de cálculo en tiempo real, par sostenido a altas velocidades, un sistema de agarre capaz de tomar y liberar piezas con rapidez , y una cinta transportadora que no se trabe durante el funcionamiento.

Se eligió la placa NodeMCU -32s con el chip ESP32 por su capacidad de procesamiento, necesaria para resolver la cinemática del robot en tiempo real, por contar con cuatro temporizadores de hardware

Descripción General del Proyecto

independientes, uno para cada uno de los tres motores y uno de reserva, por su soporte | de lectura
analógica -digital requerida por los tres encoders , por su bajo costo y por el conocimiento que ya se tenía por haber trabajado en él previamente. Contando con 38 pines, se ajusta al requerimiento del sistema y sobran pines para expansiones futuras.

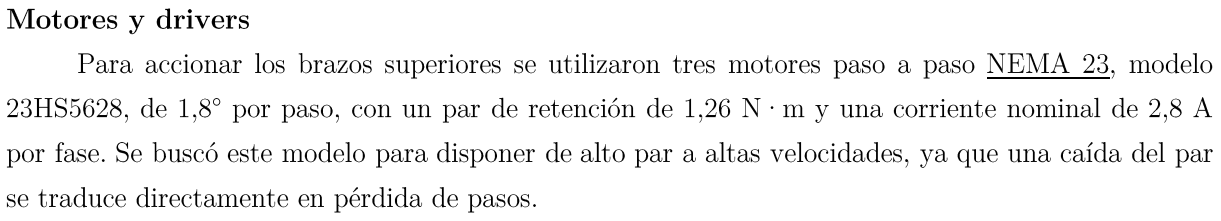
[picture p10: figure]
Motores y drivers

Para accionar los brazos superiores se utilizaron tres motores paso a paso | NEMA 23 , modelo
23HS5628, de 1,8° por paso, con un par de retención de 1,26 N·m y una corriente nominal de 2,8 A
por fase. Se buscó este modelo para disponer de alto par a altas velocidades, ya que una caída del par se traduce directamente en pérdida de pasos.
Para controlar los motores se emplearon drivers DM556. En la propuesta se había previsto | usar
TB6600, pero se descartó ya que el DM556 ofrecía un control de corriente y de micropaso | s más estable.
Admite alimentación de hasta 50 V de corriente continua y corrientes configurables entre 0,5 y 5,6 A,

Se adquirió además un conversor de niveles lógicos, previendo que las entradas de los drivers requirieran señales de 5 V; en las pruebas, los DM556 respondieron correctamente a las señales de 3,3 V del ESP32, por lo que no fue necesario incorporarlo.

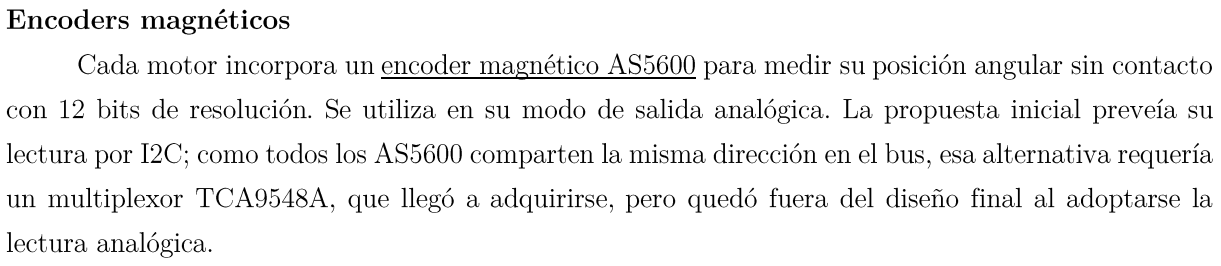
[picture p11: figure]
Encoders magnéticos; lectura analógica.

Cada motor incorpora un encoder magnético AS5600 para medir su posición angular sin contacto con 12 bits de resolución . S e utiliza en su modo de salida analógica. La propuesta inicial preveía su lectura por I2C; como todos los AS5600 comparten la misma dirección en el bus, esa alternativa requería
un multiplexor TCA9548A, que llegó a | adquirirse, pero quedó fuera del diseño final al adoptarse la
Se utilizaron tres microinterruptores | Donghai KW4 -3Z-3, de configuración SPDT, uno por eje.
Intervienen únicamente en la rutina de homing | para establecer la posición de referencia de cada motor
El agarre se resolvió con una ventosa de vacío alimentada por una | bomba de diafragma de 12 V.
Para soltar la pieza con rapidez surgió la necesidad de incorporar una electroválvula 3/2 normal cerrada

La bomba, cuyo consumo de hasta 1,2 A impide accionarla directamente desde el
microcontrolador, se conmuta mediante un módulo | MOSFET IRF520 | , que acciona también la
electroválvula . A l desactivarse, la bomba se detiene y la electroválvula libera el vacío, soltando la pieza
La cinta se acciona mediante un motorreductor de corriente continua | JGA25 -370, de 6 V y 60
rpm, con caja de engranajes metálicos y un par de 3 kg·cm, | que logran que la cinta no se trabe durante

Descripción General del Proyecto

El motor se controla por PWM mediante un driver de puente H , el DRV8833 , adecuado a su

Los rodillos de la cinta giran sobre cuatro rodamientos pequeños para reducir la fricción .

La cámara utilizada es una | Webcam USB estándar , conectada directamente a la PC. | Se eligió
por su bajo costo, disponibilidad y sencillez. Es la base para implementar un sistema de detección.
Posee resolución HD 720p a 30 cuadros por segundo.
Para iluminar la zona de la cámara se instalaron | tiras LED blancas de 12 V , adheridas bajo el
perfil 2020 que sostiene la cámara, de modo que iluminan la cinta desde arriba. Las mismas tiras | se
utilizaron para iluminar | los carteles identificatorios del proyecto, con las leyendas | “KUKO DELTA
CARBON ” y “FI -UNLZ – Developed by Reynaga De Palma ”.

La estructura de soporte se construyó con perfiles de aluminio normalizados tipo Bosch de las series 4040 y 2020 , con sus accesorios de unión (escuadras internas, escuadras triples, tuercas martillo y tapas ). Se eligieron por su rigidez estructural y su bajo peso.

La estructura se apoya sobre 4 patas de goma ajustables para darle estabilidad.

Los brazos superiores se fabricaron con aluminio reciclado de aberturas de aluminio .

Las varillas de los brazos inferiores son tubos de fibra de carbono de 4 mm de diámetro exterior y 2 mm de diámetro interior, elegidos por su bajo peso y su alta rigidez, que se unen al brazo superior
y a la plataforma móvil mediante rótulas Traxxas 5525. Inicialmente se habían adquirido otras rótulas a un proveedor internacional, pero al recibirlas se comprobó que eran de menor tamaño que el requerido, con rosca M3 en lugar de M4 y una holgura excesiva para la precisión que el mecanismo requería, por lo que se descartaron.
Los motores se fijan a la estructura con | soportes de chapa específicos para NEMA 23.
El sistema cuenta con dos fuentes de alimentación. | Primero u na fuente switching de 48 V y 7,5
El resto del sistema se alimenta desde una | fuente ATX reutilizada de una computadora, que
entrega 3,3 V, 5 V , 6 V y 12 V responsable de alimentar los encoders, la bomba, la electroválvula y las tiras LED. Los 6 V que requiere el motor de la cinta se obtienen mediante un módulo conversor regulable alojado dentro de la misma fuente.

Descripción General del Proyecto

### 4.4. Ciclo productivo

El recorrido completo de una pieza a través de la celda , desde que aparece frente a la cámara hasta que queda depositada en su destino , se puede explicar en los siguientes pasos :

1. La cámara, conectada a la PC, captura la escena de la cinta en movimiento.
2. El sistema de visión artificial detecta la pieza, mide su color y su forma, y calcula su posición.
3. En el instante en que la pieza cruza una línea de referencia fija, la PC envía al firmware un único mensaje con su posición en el eje Y, su color y su forma.
4. El firmware guarda la pieza en una cola de piezas pendientes, junto con el instante en que llegó, y toma de ella la próxima pieza alcanzable.
5. El firmware, que ya conoce la velocidad de la cinta, resuelve mediante iteración de punto fijo dónde y cuándo el brazo debe interceptar la pieza y planifica la maniobra de aproximación y descenso.
6. El robot desciende a favor del movimiento de la cinta, toca la pieza con velocidad ya igualada a la de la cinta, y la sujeta mediante la ventosa de vacío.
7. Según el modo de operación activo, el firmware dirige el brazo al tacho o a la celda de la caja que corresponde al color o la forma detectados, y libera la pieza.
8. El brazo regresa a la posición de espera, listo para repetir el ciclo con la siguiente pieza.

Este recorrido se retoma con mayor detalle técnico en el capítulo «Firmware del sistema embebido» y en el capítulo «Sistema de visión artificial».

### 4.5. Resultado final del proyecto

El resultado del proyecto es un prototipo funcional de una celda de clasificación automática, capaz de operar de forma autónoma sin detener la cinta transportadora.

El sistema ejecuta un ciclo completo: Homing inicial, detección de las piezas por visión artificial, intercepción sobre la cinta en movimiento, agarre neumático, depósito en el destino correspondiente y retorno a la posición de espera ; y lo puede hacer repetidamente sosteniendo la productividad .

Ofrece cuatro modos de operación: clasificación por color o por forma en tres depósitos; modo Box, que arma una caja de seis celdas con piezas circulares según una disposición de colores configurable; y modo Teach, que permite grabar y reproducir movimient os realizados manualmente por

Incorpora además supervisión de colisiones mediante encoders: A nte una colisión, detiene el robot, libera la pieza y recalibra su posición de manera automática .

Toda la celda se opera y supervisa desde una interfaz propia, que muestra en tiempo real el
estado de cada componente y la producción acumulada.

En conjunto, el prototipo demuestra la viabilidad y buen funcionamiento .

Arquitectura del Sistema

## 5. ARQUITECTURA DEL SISTEMA

### 5.1. Arquitectura general

El sistema KUKO Delta Carbon se organiza en tres niveles. En el nivel superior, una computadora personal procesa la imagen de la cámara para detectar y clasificar las piezas, y aloja la interfaz de
operación. En el nivel intermedio, un microcontrolador ESP32 controla el movimiento de | l robot en
tiempo real. En el nivel inferior se encuentran los actuadores y los sensores: los tres motores paso a
paso con sus drivers, el motor de la cinta transportadora, la bomba de vacío, los encoders magnéticos
y los finales de carrera.

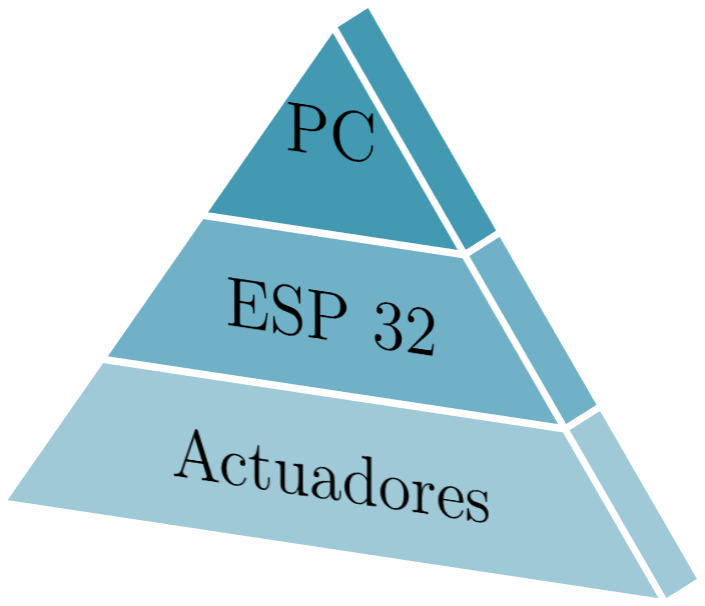
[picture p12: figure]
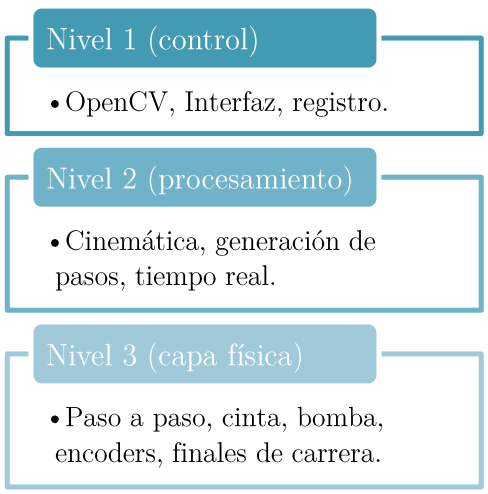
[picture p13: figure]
• OpenCV, Interfaz, registro.; Nivel 1 (control); • Cinemática, generación de pasos, tiempo real.; Nivel 2 (procesamiento); • Paso a paso, cinta, bomba, encoders, finales de carrera.; Nivel 3 (capa física)

Figura 2 – Niveles de la arquitectura del sistema.

### 5.2. Reparto de responsabilidades

Se decidió repartir las tareas entre la PC y el ESP32 | para el correcto funcionamiento del sistema.
E l microcontrolador ejecuta | todos los parámetros | de tiempo real, aquellos que no admiten
demoras de procesamiento; mientras que la PC se encarga de las tareas con | mayor necesidad de

El ESP32 coordina el ciclo de clasificación, calcula la cinemática inversa y la intercepción de cada pieza, genera los pulsos de los motores y supervisa las colisiones; la PC, por su parte, se ocupa de la visión artificial, de la interfaz de operación y del registro de la producción.

T odo aquello que no sea estrictamente necesario para mover el robot se dejó fuera del firmware para no cargar los ciclos de procesamiento y agilizar el loop principal .

E l ESP32 no calcula la cinemática directa porque no lo necesita. Para mover el robot recibe una coordenada objetivo, la convierte en ángulos mediante la cinemática inversa, y emite los pulsos correspondientes. No necesita saber “dónde está” el brazo en coordenadas cartesianas. Quien sí necesita

Arquitectura del Sistema

esa información es la interfaz para dibujar la posición del robot; por eso la cinemática directa está implementada únicamente del lado de la PC .

E l firmware tampoco lleva un registro de lo ocurrido , no sabe cuánto tiempo estuvo en cada estado ni cuándo ocurrió cada evento. Es l a PC , la que está recibiendo toda la telemetría en tiempo

Los niveles superiores se comunican mediante un enlace serie por USB. Cuando una pieza cruza
la línea de detección de la cámara, la PC envía al ESP32 su posición, su color y su forma; a partir de
ese momento, el microcontrolador resuelve de manera autónoma la intercepción, el a garre y el depósito
de la pieza. En sentido inverso, el ESP32 informa su estado | continuamente, lo que permite que la
interfaz reflej e la situación del robot en todo momento.

El tercer nivel , conformado por el conjunto de actuadores mecánicos del robot, responde a las
órdenes del microcontrolador | mediante la lógica de firmware programada, detallada en | sección
«Firmware », a través del conexionado eléctrico, desarrollado en «Diagrama eléctrico ».

### 5.3. P rotocolo de comunicación

La comunicación entre el firmware y la aplicación de PC se realiza a través de un enlace serie USB a 115200 baudios, utilizando mensajes de texto simples, de una sola línea, fáciles de interpretar tanto por un programa como por una persona observando el flujo de datos durante una prueba.

La telemetría tiene sus frecuencias fijas de actualización , y los mensajes de la PC se disparan por un evento , un comando o un ajuste. Esto permite que la interfaz de operación se mantenga siempre actualizada sin saturar la comunicación .

E l ESP32 emite de manera continua tres tipos de mensajes, cada uno | con una etiqueta y con
una frecuencia de actualización distinta según | el tipo de información que contiene:
- [T] T elemetría de movimiento (10Hz) : Informa para cada motor, el ángulo que el firmware le ordenó y el ángulo que efectivamente mide su encoder, la diferencia entre ambos (el error que vigila la supervisión de colisiones) y el umbral que se está usando en ese instante para decidir
- [E] E stado general (1Hz): Informa en qué modo de operación está el robot, cuántas piezas hay pendientes de clasificar y los contadores acumulados de producción.
- [H] Salud del sistema (2Hz): Informa si cada encoder está respondiendo correctamente, cuánta memoria libre le queda al microcontrolador y con qué frecuencia se está ejecutando el bucle

L os mensajes provenientes de la PC se pueden dividir en tres tipos :

Arquitectura del Sistema

- A viso de pieza detectada : C ada vez que una pieza cruza la línea de detección , envía su posición en el eje Y, su color y su forma, en un único mensaje. Como el aviso se emite justo en el cruce
de esa línea, la posición de la pieza en el eje X ya es conocida y no hace falta transmitirla .
- Comandos: De forma más esporádica, se envían comandos cortos de una o dos letras para pedir un cambio de modo, ajustar alguno de los parámetros de calibración del robot, o solicitar un
- Modo Teach : Mientras el operador se encuentra controlando el movimiento manual , la PC envía una dirección de movimiento que se actualiza cada 100 ms. Si la dirección deja de recibirse durante 350 ms, el firmware la descarta y el brazo se detiene.

### 5.4. Disposición del s istema físico

Los motores se encuentran montados en la parte superior de la estructura, sostenidos por una única columna rígida de la cual se extiende la base o “techo” del robot. El centro de la base de los motores define el origen del sistema de coordenadas.

El eje X es paralelo al movimiento de la cinta y positivo en el sentido de avance de las piezas; el
eje Y es transversal a ella y positivo hacia la columna | ; y el eje Z es vertical, con valores negativos hacia
abajo. Esto se detalla más adelante en la sección | «Modelo Matemático ».

A lo largo del robot, se distinguen tres zonas:

Zona de detección: L a cámara, montada por encima de la cinta, registra cada pieza al cruzar una línea fija situada 23 cm antes del centro del robo t.

Zona de intercepción : C omprendida entre 10 cm antes y 12 cm después del centro del robot, dentro de la cual el brazo puede tomar las piezas. Su asimetría responde a que cada aproximación
comienza 2 cm por detrás del punto de agarre, con lo que el recorrido efectivo de la punta r | esulta
Zona de depósito: Allí se alinean los tres tachos de clasificación, paralelos a la cinta y | ocupando
el frente del robot . En el modo Box, sobre ellos se apoya una tapa con forma de caja de seis celdas.

Las posiciones de los tachos , de la caja y la línea de detección son parámetros ajustables desde la interfaz, lo que permite recalibrarlos ante cambios en la disposición física sin reprogramar el robot.

Diseño Mecánico

## 6. DISEÑO MECÁNICO

### 6.1. Configuración cinemática y parámetros geométricos

La configuración cinemática adoptada corresponde a un robot delta clásico, con tres piernas idénticas dispuestas a 120° entre sí sobre una base triangu lar, cada una compuesta por un brazo superior rígido y un brazo inferior formado por un paralelogramo articulado. Los parámetros geométricos definitivos del robot s e muestran en la Tabla [2], y se identifican en las Imágenes [3], [4] y [5].

Parámetro | Símbolo | Valor
Longitud del brazo superior | L1 | 18,0 cm
Longitud del brazo inferior | L2 | 35,2 cm
Radio de la base fija | rB | 8,27 cm
Radio de la plataforma móvil | rE | 3,83 cm

Tabla 2 – P arámetros geométricos del robot.

Imagen 3 – Longitud del brazo superior e inferior.

Diseño Mecánico

Imagen 4 – Radio de la base fija .

Imagen 5 – Radio de la plataforma móvil .

Diseño Mecánico

### 6.2. E structura de soporte principal

La estructura de soporte principal del robot , construida con perfiles de aluminio normalizados de las series 4040 y 2020, junto con sus accesorios de unión correspondientes , se apoya sobre cuatro patas de goma antideslizante . Se ilustra en la Imagen [ 6].

Los motores se acoplan a la base fija superior , la cual está formada por una pieza modelada e impresa en 3D en PLA , abrazada por dos placas de aluminio de 4mm , una a cada lado . Con este ensamblaje, u na placa funciona a tracción y otra a compresión , logrando a partir de un material compuesto, una pieza rígida y de bajo peso.

Se buscó que la estructura sea modular y compacta, donde todo el robot sea un solo bloque. Gracias a est e enfoque, se logró tener un robot transportable y de fácil instalación.

Imagen 6 – Estructura de soporte principal.

Diseño Mecánico

### 6.3. Brazos superiores e inferiores

Cada una de las tres piernas del robot está compuesta por dos elementos: un brazo superior, de 18,0 cm de longitud, acoplado directamente al eje de su motor correspondiente y accionado dentro de
un plano vertical fijo; y un | brazo inferior , de 35,2 cm de longitud, formado por un par de varillas
paralelas unidas en sus extremos mediante articulaciones esféricas (rótulas). | Se ilustra en la Imagen [ 7].

Este par de varillas paralelas es lo que constituye, junto con el brazo superior y la base, el
paralelogramo articulado explicado en la sección « | Reseña histórica: El paralelogramo articulado por
Reymond Clavel », gracias a esto, la plataforma móvil siempre | se mantiene paralela a la base. Las
rótulas son de tipo bola y casquillo a presión, y las dos varillas de cada | brazo inferior se mantienen
unidas mediante resortes que presionan los casquillos contra las bolas, e liminando holguras.

Imagen 7 – Brazos superiores e inferiores .

### 6.4. El efector final

Como efector final se utilizó una ventosa de vacío comercial, sujeta por un soporte impreso en
3D que la abraza y que se atornilla a la plataforma móvil, montada de manera que su punta, el punto de contacto con la pieza, queda 2,8 cm por debajo del plano de la plataforma.

Al ir atornillado, el conjunto de soporte y ventosa puede reemplazarse por otro gripper sin modificar el resto del mecanismo. E n caso de cambiar lo por uno de distintas dimensiones , basta con actualizar el offset del gripper desde los ajustes. Se ilustra en la Imagen [ 8].

Diseño Mecánico

Imagen 8 – Efector con ventosa neumática .

### 6.5. Cinta transportadora

La cinta transportadora, encargada de a bastecer de piezas el área de trabajo del robot, tiene una estructura fabricada de perfiles de aluminio 2020 y piezas de impresión 3D. Se ilustra en la Imagen [ 9].

Como banda se utilizó una lona reciclada | que fue recortada a medida y cosida. | Se ilustra en la
Imagen [ 10].

P ara moverla se colocó un moto rreductor de corriente continua con control PWM, que permite ajustar la velocidad de la cinta al valor más adecuado para el funcionamiento del robot.

Imagen 9 – Conjunto cinta transportadora.

Diseño Mecánico

Imagen 10 – Banda de lona reciclada.

### 6.6. Piezas fabricadas por impresión 3D

Mediante impresión 3D se fabricaron tanto elementos funcionales como estéticos.

Qué no se imprimió
Para decidir qué piezas podían fabricarse de esta manera, se evaluó la exigencia estructural de
cada una . Se imprimieron aquellas que no est uvieran sometidas a esfuerzos elevados, mientras que los elementos de mayor responsabilidad estructural se resolvieron con perfiles de aluminio normalizados y componentes comerciales, como los acoples de los brazos superiores a los motores; también las rótulas o rodamientos que se encuentran sometidos a desgaste por movimiento repetitivo son comerciales.

Todas las piezas impresas en 3D del proyecto son de diseño propio .

Algunas de ellas se identificaron con el nombre del proyecto, KUKO , seguido de su función.

Se defini ó una línea estética que se mantuvo para todas las piezas que componen el robot para

Diseño Mecánico

Pieza modelada e impresa en 3D, abrazada por dos | placas de aluminio, una a cada lado. Es la
pieza sobre la que se montan los motores y los finales de carrera | con sus soportes. Se ilustra en la

Imagen 11 – Base fija de plástico abrazada con dos chapas de aluminio.

Fabricarla en PLA contribuye a reducir la masa en movimiento, | su diseño ahuecado maximiza
la reducción de peso , que es lo que le permite al delta alcanzar aceleraciones elevadas | . R ecibe los tres
brazos inferiore s en sus vértices mediante rótulas, y sostiene en su centro la herramienta de trabajo (gripper) . Se ilustra en la Imagen [1 2].

Imagen 12 – Plataforma móvil .

Diseño Mecánico

Pieza impresa en 3D en 2 partes que abraza la ventosa comercial y la fija a la plataforma móvil mediante tornillos. Se ilustra en la Imagen [1 3].

Imagen 13 – Soporte de ventosa .

### 6.6.4. Soporte de los finales de carrera

Pieza que fija cada final de carrera a la base. Se optó por imprimirla porque, a partir del modelado 3D, se generó con el ángulo preciso que necesita ba el brazo superior para realizar el homing contra el switch final de carrera correctamente. Se ilustra en la Imagen [1 4].

Imagen 14 – Porta final de carrera.

### 6.6.5. He rramienta de armado de varillas

La igualdad de largo entre las varillas es una condición fundamental para que la plataforma móvil se mantenga paralela a la base fija . T odas las varillas deben tener exactamente la misma longitud, una pequeña diferencia alcanza para que la plataforma quede inclinada y el mecanismo deje de comportarse

Diseño Mecánico

Por eso, su fabricación es una de las tareas más críticas. Un error en esta etapa hubiera obligado a rehacer los brazos inferiores , aumentando el gasto de tiempo y recursos.

Para resolverl o se diseñó una herramienta de armado , la cual fue | impresa en 3D. | Esta
herramienta aloja dos varillas roscadas, y | permite insertar las rótulas en cada varilla a | una distancia
exacta, de modo que todas las varillas qued en con idéntica longitud entre centros.

No forma parte del robot terminado, pero fue fundamental porque garantizó un correcto armado.

Se ilustra en las Imágenes [1 5], [16] y [1 7].

Imagen 15 – Herramienta de armado de brazo inferior precisa.

Imagen 16 – Previo al armado de brazo inferior, conjunto de varilla con rotulas.

Imagen 17 – Armado final de brazo inferior .

Diseño Mecánico

### 6.6.6. C ompartimentos por color y forma

Son tres recipientes, cada uno correspondiente a un color y a una forma de pieza, diseñados para que las piezas depositadas por el robot se deslicen por una rampa interna y se acumulen en su interior.

Cada uno tiene al frente una compuerta deslizante hacia arriba, que permite retirar las piezas acumuladas. E n el frente de la compuerta se indica el color del compartimento como “ RED, GREEN y BLUE ” (rojo, verde y azul) y la manija con la que se la levanta lleva el símbolo de la forma “SQUARE,
HEXAGON | y CIRCLE ” (cuadrado, hexágono y círculo) , de modo que los mismos compartimentos
sirven tanto para el modo de clasificación por color y | como para el de clasificación por forma.

Se ilustra en la Imagen [1 8].

Imagen 18 – Compartimentos frontales clasificadores por color y forma .

Plataforma clasificadora del modo de operación Box, modelada e impresa en 3D. Está dividida en 6 celdas , dispuestas en 2 filas y 3 columnas. Se encastra sobre el compartimento de piezas color GREEN , junto a la cinta, lo que la deja al alcance del robot. En ella el robot deposita las piezas circulares según una disposición de colores configurable. Se ilustra en la Imagen [1 9].

Imagen 19 – Plataforma clasificadora del modo de operación Box .

Diseño Mecánico

### 6.6.8. Kuko Cam

Adaptador que sujeta la cámara en el extremo del brazo lateral de la estructura, de modo que la cámara queda sobre la cinta, mirando hacia ella, para detectar las piezas. Se ilustra en la Imagen [ 20].

Imagen 20 – Soporte adaptador de cámara.

### 6.6.9. Kuko Trash

Compartimento perforado, que simula ser un cesto, ubicad o al final de la cinta transportadora, donde caen y se almacenan las piezas que el robot no tomó y que la cinta traslada hasta el final.

Se ilustra en la Imagen [ 21].

Imagen 21 – Compartimento perforado para piezas no alcanzadas.

Diseño Mecánico

### 6.6.10. Caja electrónica

Caja ubicada debajo de la cinta, que aloja y agrupa la electrónica del sistema | , el NodeMCU -32S
con su shield , el mosfet que comanda la bomba de vacío y el controlador del motor | reductor de la cinta
transportadora. Se ilustra en la Imagen [2 2].

Imagen 22 – Caja electrónica.

### 6.6.11. Soportes y accesorios de montaje

La impresión 3D permitió realizar cada soporte a la medida exacta del componente que sostiene. Se imprimieron los soportes de los siguientes elementos, que se montan sobre un perfil 4040 de la estructura de soporte principal:

- | Motorreductor de corriente continua, que mueve la banda de la cinta. | [23]
- | Conector de entrada de la fuente de alimentación. | [24]
- Conector USB macho de la cámara. [25]
- Bomba de vacío. [26]
- Electroválvula. [26]
Imagen 23 – Porta motor DC . | Imagen 24 – Porta conector de alimentación 220v .

Diseño Mecánico

Imagen 25 – Porta conector cable USB macho de cámara.

Imagen 26 – Porta electroválvula y bomba de vacío.

También se imprimieron algunos accesorios como :

- Organizadores de cable, que se montan sobre el mismo perfil 4040 . [27] y [2 8]
- | Un adaptador que permite unir un perfil 4040 con un 2020. | [29]
- Ángulos en “L”, que permiten sostener la cinta . [30]
- Porta rodillos de la cinta . [31]
- Tensores de cinta , ajustables con tornillos. [32]
- Acoplamiento entre el motorreductor y la varilla roscada . [33]
- Rodillos de la cinta . [34]
- Porta Enconder. [35]
- Separadores de varilla. [36]
- Porta resortes. [37]
Imagen 27 – Organizador de cable horizontal. | Imagen 28 – Organizador de cable vertical.

Diseño Mecánico

Imagen 29 – Adaptador perfil 4040 a 2020 . | Imagen 30 – Ángulos “L” porta cinta transportadora.
Imagen 31 – Porta rodillos. | Imagen 32 – Tensor de cinta transportadora.
Imagen 33 – Acople de motor -varilla roscada . | Imagen 34 – Rodillo de cinta .

Diseño Mecánico

Imagen 35 – Porta Encoder. | Imagen 36 – Separadores de varilla .

Imagen 37 – Porta resortes .

6.6.12. Tuercas martillos, porta tuercas | , cartelería y piezas de muestras
Se imprimieron tuercas martillo | para perfil 4040 | con una tuerca metálica insertada | [38],
destinadas a piezas que no soportan esfuerzo , para evitarnos de comprar tuercas martillos por su baja
disponibilidad y alto costo comparativamente | ; las uniones estructurales de los perfiles | mantienen
tuercas martillo metálicas . También se imprimieron tuercas martillo para perfil 2020 [39], que permiten sostener accesorios en ese perfil .

L os separadores de los brazos inferiore s mantienen a las dos varillas de cada conjunto paralelas,

L os porta -resortes sostienen los resortes firmes en las varillas cuando están en movimiento.

También fueron impresas las tapas de la cinta transportadora [40] y la cartelería identificatoria del proyecto, el panel con el nombre del robot [41], las siglas de la facultad y los autores, ubicado detrás

Por último, se imprimieron las piezas geométricas. Son cuadradas, hexagonales y circulares , que

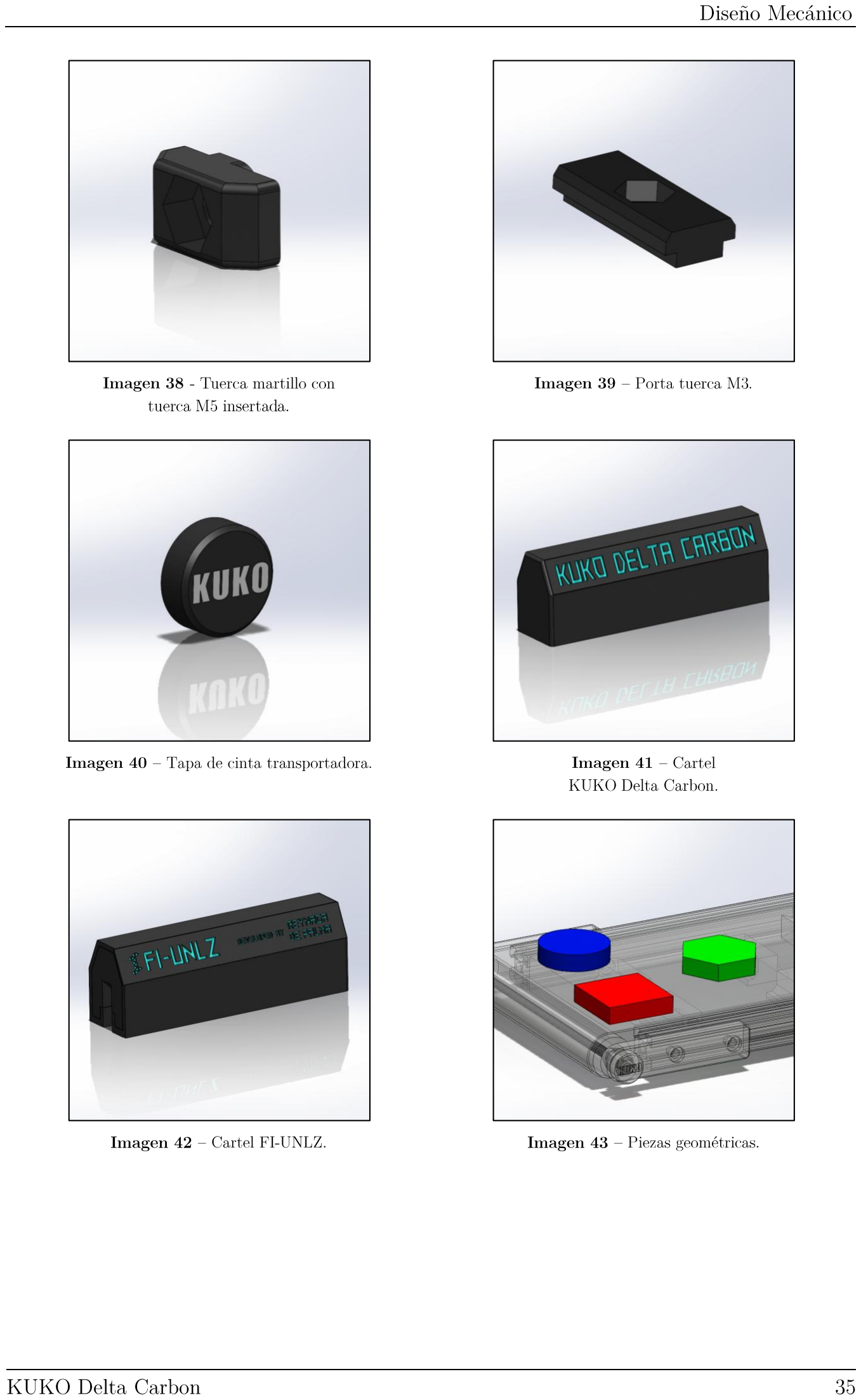
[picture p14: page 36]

Diseño Mecánico

Imagen 38 - T uerca martillo con tuerca M5 insertada.

Imagen 39 – Porta tuerca M3 .

Imagen 40 – Tapa de cinta transportadora . | Imagen 41 – Cartel KUKO Delta Carbon.
Imagen 42 – Cartel FI -UNLZ . | Imagen 43 – Piezas geométricas .

Diseño Eléctrico y Electrónico

### 7.1. Diagrama de conexión

El esquema de conexión eléctrica que se desarrolló en Fritzing sirvió inicialmente para diseñar el conexionado, ubicar componentes y pensar el cableado necesario.

El diagrama ha sido | modificado a lo largo del desarrollo | por problemas de interferencia
electromagnética, por componentes que se agregaron y por otros que no se utilizaron.

La versión final terminó como un esquemático representativo de la conexión real de todos los componentes eléctricos del robot . En él se detalla la conexión del microcontrolador ESP32 con los drivers de motor, los encoders magnéticos, los finales de carrera, el sistema neumático y el módulo de

El diagrama completo se incluye como Figura [ 3].

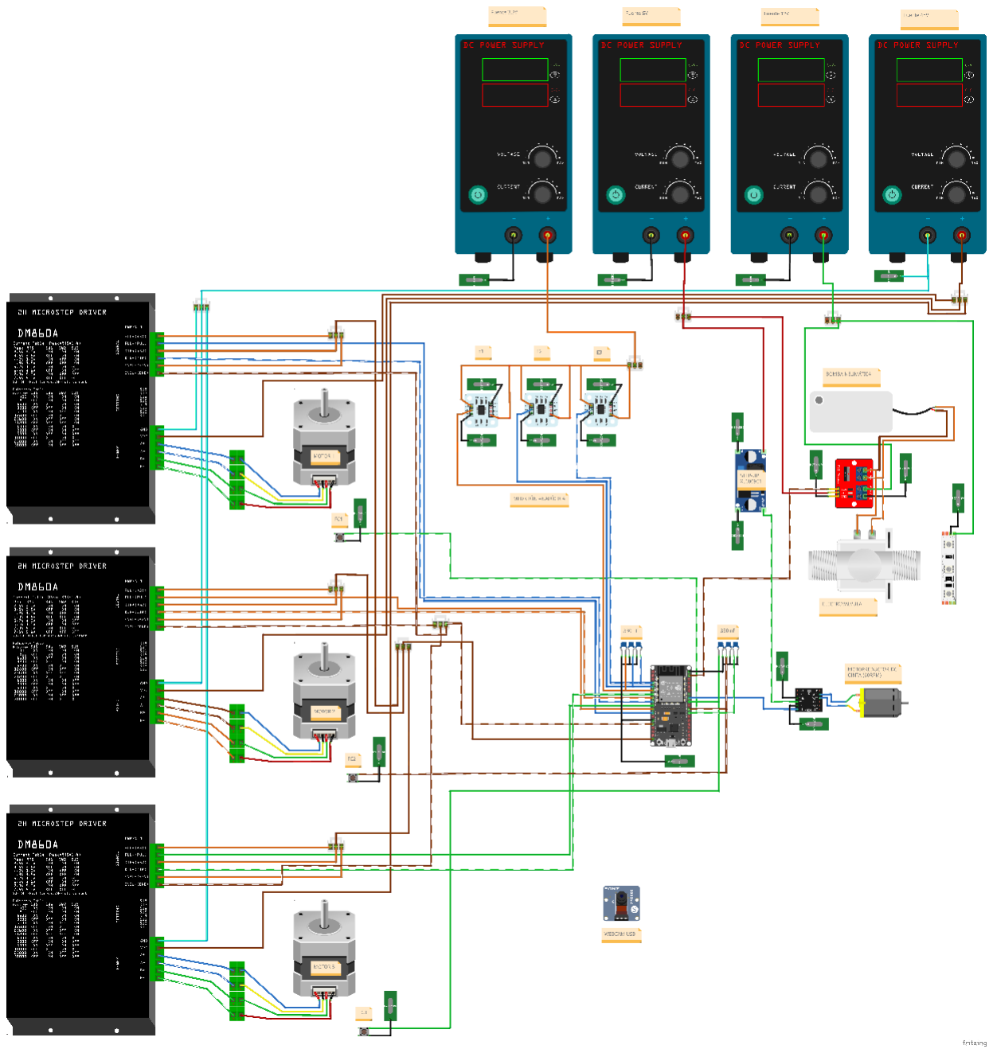
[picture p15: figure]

Figura 3 - Diagrama eléctrico.

Diseño Eléctrico y Electrónico

### 7.2. Alimentación y niveles de tensión

El sistema requiere distintos niveles de tensión según el subsistema , usando dos fuentes y el USB

La alimentación de la placa NodeMCU | -32S surge del puerto USB de la PC donde se esté
ejecutando el programa . Aprovecha el USB de la comunicación serie para mantenerse encendid | a. Si se
desconecta el USB, la placa se apaga y el robot queda estático, sin su parte de lógica de control.
Se utiliza también el pin | de 5 V - V IN (tensión de entrada de l puerto USB) de la placa para
darle energía a los optoacopladores de los drivers, alojados en su parte lógica. | E s conveniente para
evitar fallos de funcionamiento por | perturbaciones el éctricas. Esto se detalla en la sección

L a parte de potencia de l os drivers DM556 operan con la fuente de mayor tensión de corriente continua , que entrega 48 V pico. Se trata de una fuente switching que entrega hasta 7,5 A. Se ilustra

Una tensión mayor permite que el driver establezca la corriente en las bobinas del motor en
menor tiempo, por lo que el par se mantiene a velocidades más altas. Una corriente mayor, a su vez, asegura que la fuente no llegue a su límite cuando los tres motores aceleran simultáneamente.

Se decidió ajustarla con su regulador interno para que entregue 43 V . De esta manera se protegen los drivers y no se exige la fuente por demás.

Imagen 44 – Fuente Switching 48v 7,5 A .

Diseño Eléctrico y Electrónico

El resto de los componentes del robot es alimentado por una fuente ATX reciclada de una computadora. Se ilustra en la Imagen [4 5]. Entrega originalmente tensiones de 3.3 V, 5 V y 12 V. Se le agregó un conversor de tensión para regular una cuarta salida , la cual para nuestro proyecto se ajustó

Posee alta potencia, con distintos niveles de corriente para cada nivel de tensión, siempre muy
por encima de los requerimientos de nuestro sistema. Se eligió por la variedad de tensiones que entrega, y principalmente porque es de origen reciclado , lo que evitó gastos.

De 3.3 V se alimentan los encoders magnéticos modelo AS5600 .

De 5 V se alimenta la lógica d el mosfet de la bomba de vacío y de la electroválvula neumática.

De 6 V se alimenta el motorreductor de la cinta transportadora.

De 12V se alimenta n las tiras LED y | el mosfet, pero en su parte de potencia .
Imagen 45 - ATX reciclada de una computadora | .

### 7.3. Etapa de potencia de los motores

Los tres motores paso a paso NEMA 23 se accionan mediante tres drivers DM556, los cuales comparten una única señal de habilitación (enable), de modo que pueden activarse o desactivarse en

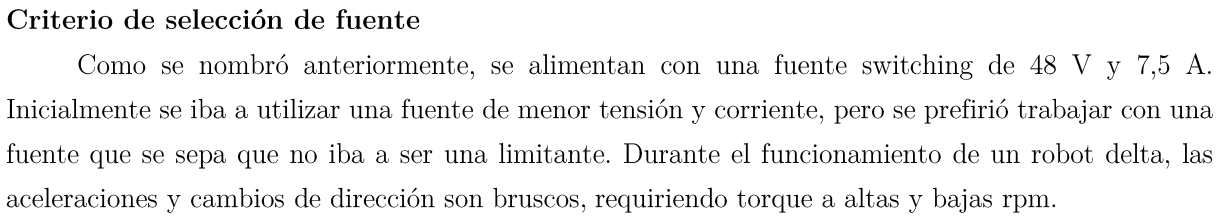
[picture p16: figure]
Criterio de selección de fuente

Como se nombró anteriormente, se alimentan con una fuente switching de 48 V y 7,5 A. Inicialmente se iba a utilizar una fuente de menor tensión y corriente, pero se prefirió trabajar con una fuente que se sepa que no iba a ser una limitante. Durante el funcionamiento de un robot delta, las aceleraciones y cambios de dirección son bruscos, requiriendo torque a altas y bajas rpm.

Diseño Eléctrico y Electrónico

Nema 23 vs Nema 17
A diferencia de los motores N EMA 17, habituales en el desarrollo de prototipos, los NEMA 23 tienen bobinados de mayor tamaño y, en consecuencia, una inductancia más alta. Esto hace que la corriente tarde más en establecerse en cada bobina y que el par comience a caer a velocidades más bajas, lo que en principio constituye una desventaja. Sin embargo, alimentados con una tensión adecuada, como los 48 V de la fuente seleccionada, la corriente se establece con la rapidez necesaria y el motor conserva su torque, que en este modelo alcanza 1,26 N·m, más del doble del que ofrecen los NEMA 17 más comunes. Esto permite mover el robot a una alta velocidad sin perder pasos.

Los drivers DM556 [46], se encuentran configurados a 10.000 micropasos por vuelta y corriente de 2,7 A máximo , y el modo de Half -Current activado . Para conseguirlo, se utilizaron los switches de configuración y las tablas de referencia . Se detalla en la Tabla [ 3].

SW1 | SW2 | SW3 | SW4 | SW5 | SW6 | SW7 | SW8
ON | OFF | ON | OFF | OFF | ON | OFF | OFF
Tabla 3 – Configuración de switch en Driver | DM556

Imagen 46 – Driver DM556 .

Diseño Eléctrico y Electrónico

### 7.4. Sensado: encoders y finales de carrera

Cada motor cuenta con un encoder magnético AS5600 acoplado por detrás, mediante un soporte impreso en 3D . Se utilizaron en su modo de salida analógica siendo leídos por el conversor analógico -digital del ESP32. La Propuesta Final preveía leerlos por I2C a través de un multiplexor TCA9548A,
y esa fue la configuración empleada durante la primera etapa del desarrollo, hasta que se reemplazó
por la lectura analógica. Se ilustra en la Imagen [ 47].

Los encoders no participan del control de posición del robot, que se realiza a lazo abierto por
conteo de micropasos, sino exclusivamente de la supervisión de colisiones. Si bien la Propuesta Inicial contemplaba un control a lazo cerrado, la lectura analógica de los encoders presenta errores de varios
grados, originados | por el ruido eléctrico , se detalla | más adelante en la sección | «Interferencia
electromagnética». Estos errores se fueron reduciendo mediante calibración y filtrado, pero siguen
siendo muy superiores a la resolución del conteo de micropasos (0,036° con 10.000 micropasos) . C errar el lazo con esa medición habría empeorado la precisión del posicionamiento en lugar de mejorarla.

Los tres finales de carrera, uno por motor, se utilizan únicamente durante la rutina de homing,
para establecer la posición de referencia de cada eje al encender el sistema; fuera de esa rutina, no intervienen en el funcionamiento normal del robot. Se ilustra en la Imagen [ 48].
Imagen 47 – Enconder AS5600 | Imagen 48 – Final de carrera

### 7.5. Sistema neumático

El sistema de agarre por vacío está compuesto por una bomba neumática | [49], encargada de
generar el vacío en la ventosa, y una electroválvula | [50], encargada de liberar rápidamente ese vacío
para soltar la pieza en el momento de la clasificación. La conmutación | tanto de la bomba como de la
electroválvula se realiza mediante un módulo mosfet IRF520, comandado directamente por el

Diseño Eléctrico y Electrónico

Inicialmente , el sistema neumático no incluía | una electroválvula . Sin embargo, | las primeras
pruebas realizadas sin ella mostraron que su ausencia constituía una limitación | para el funcionamiento
del robot por su retraso para soltar la s piezas, por lo que se decidió incorporarla.

Una vez incorporada la electroválvula , el sistema neumático funcionó eficazmente. Se buscó que sea de 12 V , normal abierta y de acción directa para que se active con la misma señal que la bomba.
Gracias a eso no tuvimos que hacer grandes cambios en | el conexionado para incorporarla.
Imagen 49 - Bomba neumática | Imagen 50 - Electroválvula

### 7.6. Asignación de pines del microcontrolador

La placa NodeMCU -32S dispone de 38 pines en total. Posee 32 pines de uso general (GPIO ), 3 GND , 2 de alimentación (3.3 V y 5 V) y 1 de Reset (EN).

No todos los pines GPIO pueden usarse libremente, por lo que se tuvo en cuenta lo siguiente:

- GPIO 34, 35, 36 y 39 : 4 pines solo entrada , sin resistencias pull -up ni pull -down.
- Se aprovecharon algunos de los 16 ADC para convertir señales analógicas a digitales.
- Se evitaron pines críticos, que pueden generar errores en el booteo o inconsistencias.

No se utilizaron los GPIO 6, 7, 8, 9, 10 y 11 porque están conectados a la memoria flash interna del módulo. Si se utilizaran, podrían reiniciar la placa.

Los GPIO 1 y 3 corresponden a la UART0, que se utiliza para la comunicación serie con la PC , quedaron libres para evitar problemas de comunicación .

Los GPIO 0, 2, 5, 12 y 15 son pines de configuración de arranque: su nivel lógico se lee al encender la placa, y una carga conectada puede impedir que la placa arranque.

Quedan 19 pines de uso seguro . La asignación se definió a partir del requerimiento de cada señal:

Diseño Eléctrico y Electrónico

Encoders: Se n ecesita una entrada analógica, por lo que se conectaron a los GPIO 35, 34 y 39, canales del ADC1 que además son de solo entrada. Así, los sensores no ocupan pines bidireccionales,

Finales de carrera : Son entradas digitales que utilizan la resistencia de pull | -up interna del
microcontrolador, por lo que no pueden ubicarse en los pines de solo entrada, que carecen de ella. Se
Drivers de los motores : Se usaron GPIO de entrada/salida. | L as señales de pulso “STEP ” en
GPIO 14, 27 y 26, dirección “DIR ” en GPIO 25, 33 y 32 y habilitación | “ENA ” en GPIO 13 compartida

Cinta y sistema neumático : E l motor de la cinta se controla con una salida PWM en el GPIO
19, y el Mosfet que acciona la bomba y la electroválvula | utiliza la salida digital del GPIO 23.
La asignación resultante agrupa las señales a cada lado de la placa | , se ilustra en la Figura [4].
- De un lado el sistema de movimiento : encoders y drivers .
- Del otro lado los periféricos de la celda : bomba + electroválvula , cinta y finales de carrera.

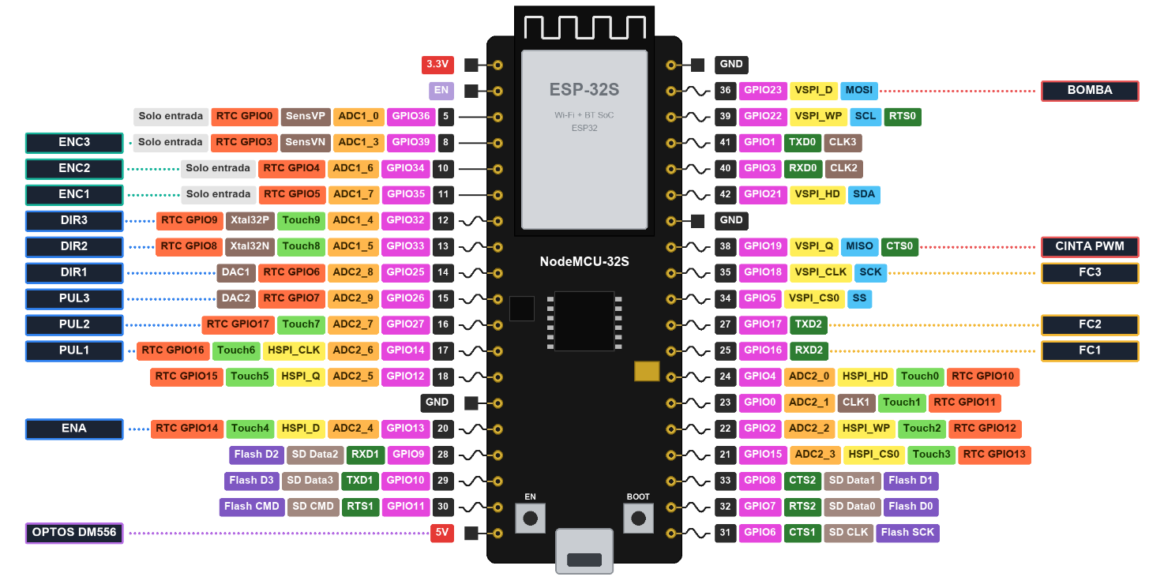
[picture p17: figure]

Figura 4 – Asignación de pines.

El sistema utiliza quince pines y deja cuatro libres de uso seguro: los GPIO 21 y 22, que
corresponden al bus I2C; el GPIO 4; y el GPIO 36 .

Estos pines dejan margen para futuras ampliaciones , como pueden ser, agregar un cuarto eje de rotación para el gripper o un sensor de vacío .

Diseño Eléctrico y Electrónico

### 7.7. Interferencia electromagnética

La interferencia electromagnética fue uno de los problemas más importantes del desarrollo , afectó a varios subsistemas a la vez, demandó un tiempo considerable y no se resolvió con una única medida,

Origen del ruido : Mediante mediciones con osciloscopio realizadas en la facultad, se identificó como fuente principal de ruido a la fuente switching de 48 V que alimenta a los drivers. El ruido que generaba llegaba a los drivers y se propagaba por el resto del circuito, afectando a las señales de menor nivel. Reemplazar la fuente no era viable por razones de presupuesto y de tiempo, por lo que se optó por conservarla y mitigar sus efectos.

Encoders: El ruido provocaba la pérdida de la comunicación I2C con los encoders, lo que llevó a
abandonar ese bus , por eso no se terminó usando | el multiplexor TCA9548A | . Se utilizó | la lectura
analógica. Esta lectura también se ve afectada por el ruido, | pero es capaz de filtrarse , por lo que se
incorporaron capacitores de 330 nF en | sus entradas analógicas. Como no resultaron suficientes por sí
solos, la señal también se filtra por software , cada lectura promedia dieciséis muestras consecutivas y luego se suaviza mediante un filtro exponencial.

Finales de carrera : Antes de filtrarlos, los finales de carrera registraban activaciones falsas provocadas por el ruido. La incorporación de capacitores de 330 nF en sus entradas eliminó esos falsos

Conmutación de la bomba : Una segunda perturbación, independiente de la fuente de los drivers, aparece al conmutar la bomba de vacío , su consumo produce una caída de tensión en la alimentación de los encoders que desplaza las tres lecturas simultáneamente, sin que el robot se haya movido. Esta perturbación la solucionamos por software, aunque se podría mitigar con diodos o capacitores. No se mitigó porque el sistema funciona correctamente con un arreglo por software y modificar el cableado hubiera requerido más tiempo.

Conexión de masas : En un principio, la estructura de perfilería de aluminio se utilizó como conductor de masa, lo que generaba diferencias de potencial entre distintos puntos del circuito e interferencias entre componentes. Para resolverlo se implementó una conexión de masa en estrella , todos los conductores se aislaron de la estructura, y las masas de la etapa de potencia y de la lógica se cablearon por separado, uniéndose únicamente en el punto central de la estrella.

Optoacopladores de drivers : L a alimentación de las entradas optoacopladas de los drivers | se
realiza desde la propia placa con el pin 5 V (VIN). | Si la señal se compara sobre su propia tensión de
alimentación, nunca se verá afectada por diferencias de potencial entre masas de distintas fuentes. E | l
optoacoplador cumple su función de aislar la lógica de control de la etapa de potencia.

La combinación de estas medidas mitigó los problemas eléctricos y permitió alcanzar un sistema

Modelo Matemático

## 8. MODELO MATEMÁTICO

### 8.1. S istema de referencia y convenciones

El desarrollo matemático requiere fija r un sistema de coordenadas de referencia , y disponer las tres piernas del robot respecto a ese sistema .

El origen se ubica en el centro de la base fija, con el plano XY horizontal y el eje Z vertical , positivo hacia arriba. Como el robot trabaja colgando hacia abajo desde su base, todas las coordenadas

El eje X es paralelo al movimiento de la cinta y positivo en el sentido de avance de las piezas; el eje Y es transversal a ella y positivo hacia la columna .

Los tres motores se colocaron a 120° entre sí. Medidos desde el eje X positivo, en sentido
antihorario y desde arriba, el motor 3 se ubica a 270° | (sobre el eje Y ), el motor 1 a 150° y el motor 2
a 30°. Esta convención es la que se usa en el desarrollo de la cinemática inversa y directa. | Se ilustra en

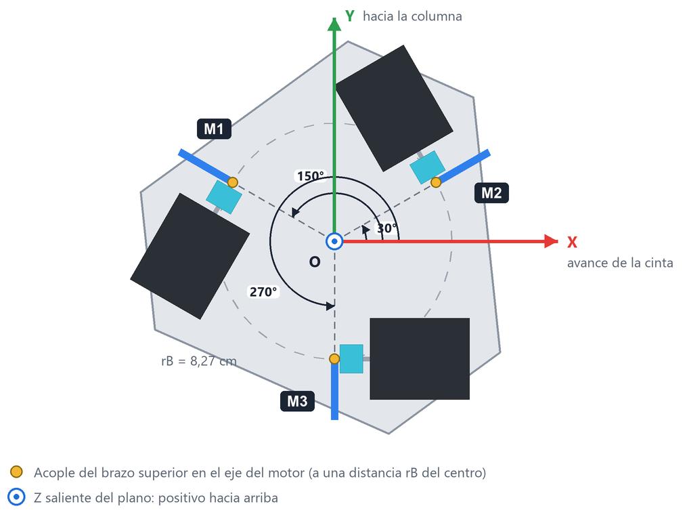
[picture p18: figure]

Figura 5 – Ubicación de los motores en el plano XY | .

### 8.2. Parámetros geométricos

Los cuatro parámetros geométricos que definen por completo la cinemática del robot son:

- L a longitud del brazo superior L1 y del brazo inferior L2
- E l radio de la base fija rB y el de la plataforma móvil rE

Las dimensiones del robot se detallan en la sección «Diseño Geométrico ».

Modelo Matemático

E l resultado de la cinemática brinda la posición d el centro de la plataforma móvil , por lo que se le debe sumar e l desplazamiento desde ese punto, hasta la punta de la herramienta .

L a ventosa se encuentra 2,8 cm por debajo, por lo que, al comienzo de la cinemática inversa, se resta ese valor de la coordenada pedida .

### 8.3. Diagrama Cinemática inversa

El problema de la cinemática inversa consiste en, dada la posición deseada de la punta | P =
(x, y, z), hallar los tres ángulos θ1, θ2, θ3 que debe adoptar cada motor. El método empleado es el de intersección de circunferencias. G racias al paralelogramo articulado, las tres piernas son cinemáticamente independientes entre sí, de modo que el problema se puede resolver una pierna a la

El brazo superior de cada pierna gira siempre dentro de un plano vertical fijo. Por ejemplo, p ara la pierna 3 , ubicada sobre el eje Y, ese plano es exactamente x = 0.

Las otras dos piernas son idénticas, salvo por una rotación alrededor del eje Z. En lugar de rotar todo el mecanismo para cada pierna, resulta mucho más simple rotar el punto objetivo, lo que es equivalente y computacionalmente más económico:
(

xi
yi

) = (

cos αi | − sin αi
sin αi | cos αi

) (

x
y

) , α1 = +120°, α2 = −120°, α3 = 0°

Con esta rotación, el problema de las tres piernas se reduce a resolver tres veces el mismo problema, pero cambiando el punto de entrada.

### 8.3.2. Ubicación del codo

- | Estar a una distancia L1 = 18 cm del eje del motor | . Como el brazo superior es rígido y gira
dentro de un plano vertical. El codo solo puede estar, entonces, sobre una circunferencia
| centrada en el motor.
- Estar a una distancia L2 = 35,2 cm del punto donde el brazo inferior se une a la plataforma móvil. Ese punto no es el centro de la plataforma sino su borde, por lo que el objetivo se desplaza previamente una distancia rE . Como el brazo inferior termina en rótulas, puede inclinarse en cualquier dirección, de modo que esta condición define una esfera de radio L2
| centrada en el punto de unión.
El codo se ubica , entonces, donde la circunferencia del brazo superior corta | la esfera del brazo
inferior. Para resolverlo dentro del plano de la pierna, se corta la esfera con ese plano, lo que da una segunda circunferencia de radio √(L2² − x₀
²), donde x ₀ es la distancia del punto de uni ón al plano de
la pierna. Cuando el brazo inferior se inclina hacia un costado, esa circunferencia es m | ás pequeña que
L2: vista desde el plano de la pierna, la barra parece m | ás corta. El codo se encuentra donde se cruzan
ambas circunferencias, y hallarlo se reduce a resolver una ecuación de segundo grado.

Modelo Matemático

### 8.3.3. Elección de la solución y cálculo del ángulo

Dos circunferencias pueden cortarse en dos puntos, tocarse en uno solo o no cortarse | .
- | Si no se cortan, el punto objetivo está fuera del alcance del robot | .
- Si se tocan en un único punto, el brazo queda completamente estirado, una posición límite que conviene evitar .
- | Si se cortan en dos puntos, existen dos posiciones posibles para el codo: | hacia adentro o
hacia afuera . Ambas son matemáticamente válidas, pero el robot solo puede adoptar la posición con el codo hacia afuera, de modo que siempre se elige esa.

Con el codo ya ubicado, el ángulo del motor es el ángulo que forma el brazo superior con la horizontal. Se ilustra en la Figura [6].

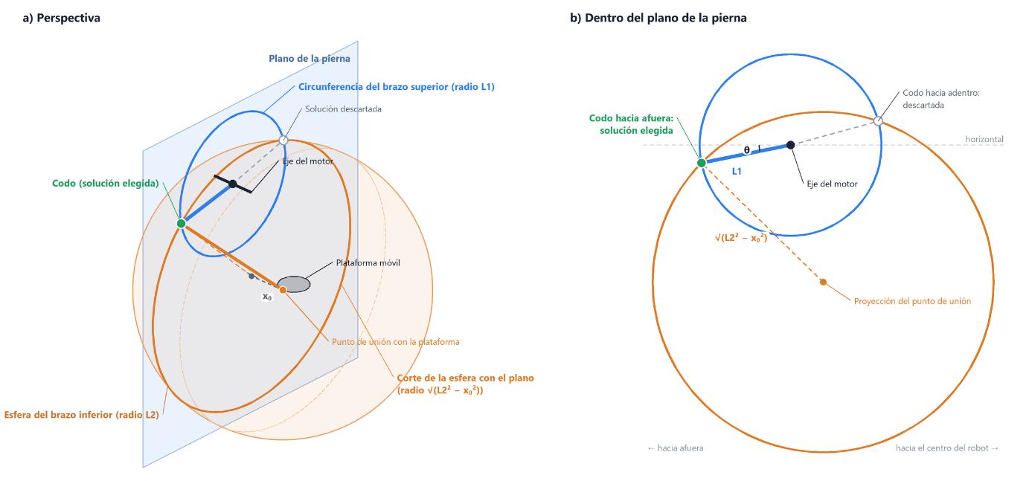
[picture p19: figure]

Figura 6 - Cinemática inversa .

### 8.3.4. Límites articulares y puntos inalcanzables

Que exista una solución matemática no garantiza que el robot pueda adoptar esa posición. Por eso, además de los puntos fuera de alcance, el cálculo rechaza aquellos que exigirían a algún motor un ángulo fuera de los límites definidos, de ±50°. A su vez, el área de trabajo se acotó a la zona validada sobre el robot real, para no exigir a las rótulas más allá de su límite físico. Ante cualquier punto inalcanzable, el sistema mantiene los motores quietos e informa que el punto no puede alcanzarse.

### 8.3.2. Conversión de ángulo a micropasos

Los drivers DM556 están configurados a 10.000 micropasos por vuelta completa, de modo que la conversión de un ángulo en grados a micropasos es:

N = round (θ ⋅

10 000
360° )

Esto define una resolución angular de 0,036° por micropaso, que sobre el brazo superior de 18 cm equivale a un desplazamiento del codo de 0,11 mm.

Modelo Matemático

### 8.4. C inemática directa

El problema de la cinemática directa es el inverso del anterior: dados los tres ángulos θ1, θ2, θ3, hallar la posición de la punta P = (x, y, z). La interfaz de operación la utiliza para dibujar en pantalla
la posición real del robot . E n un mecanismo paralelo este problema es más difícil que la inversa (al revés de lo que ocurre en un robot serie ), porque las tres condiciones geométricas deben satisfacerse a la vez sobre un único punto, y no se pueden resolver por separado como en la sección anterior. Se resuelve por trilateración.

### 8.4.1. Trilateración

Si cada codo se desplaza una distancia rE hacia el centro del robot, las tres esferas que forman los brazos inferiores pasan a cortarse directamente en el centro de la plataforma. El problema queda reducido a hallar el punto que está a una distancia L2 de tres puntos conocidos.

Tres esferas se cortan, en general, en dos puntos, simétricos respecto del plano que forman los tres codos: uno queda por debajo de ese plano, con la plataforma colgando de los brazos, y el otro por encima, en una postura que el robot no puede adoptar. Por eso se toma siempre el de menor altura.

Planteado en ecuaciones el problema se reduce, igual que en la cinemática inversa, a una ecuación de segundo grado. Se ilustra en la Figura [7].

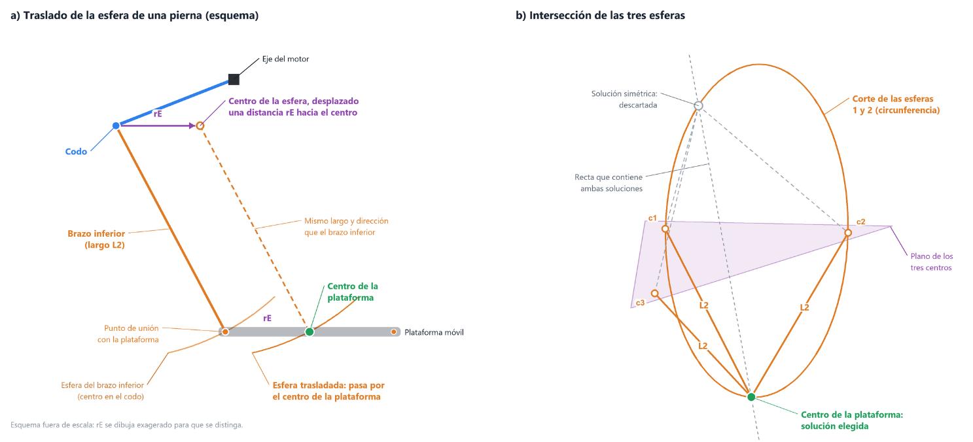
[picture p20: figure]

Figura 7 - Cinemática directa por trilateración .

### 8.5. E spacio de trabajo

El cálculo del volumen de trabajo no fue necesario durante el desarrollo. Como se contaba con
un modelo 3D fiel a las medidas reales, se pudo estudiar de forma experimental el alcance del efector probando distintas longitudes para los brazos del delta. También se tomaron como referencia diseños

Modelo Matemático

Una vez definidas las longitudes de los brazos superiores e inferiores, se armaron con las rótulas
y se hicieron pruebas físicas , se movió el robot a mano para identificar en qué posiciones empezaba a trabarse alguna articulación. Así se determinó la zona en la que el robot funciona sin trabarse, y el
volumen de trabajo se limitó por software a una región más chica, que se sabía que era alcanzable, para dejar un margen de seguridad y proteger los componentes.

Los límites principales de ese volumen son el plano de la cinta, que restringe el desplazamiento
en Z, y la columna de la estructura, que restringe el desplazamiento en Y positivo.

### 8.5.1. Determinación del volumen alcanzable

El volumen de trabajo se calculó después de construir y poner en marcha el robot, como verificación de su geometría. Durante el desarrollo no pudo calcularse porque se desconocía el ángulo máximo que admiten las rótulas. Al ser piezas de autos RC y no de uso robótico, el fabricante no publica ese dato, y tampoco se contaba con un método para medirlo con precisión.

Con el robot en marcha, se calculó que, en las zonas más alejadas donde agarra piezas sin trabarse, las rótulas llegan a 27,9° de inclinación. Por lo tanto, su ángulo máximo es al menos ese valor, y se
adoptó 30° como supuesto para calcular el volumen alcanzable.

Para el cálculo, el espacio se dividió en una grilla de puntos. En cada punto se evaluó si la cinemática inversa tiene una solución válida en las tres piernas a la vez, sin que ningún brazo supere su final de carrera ni ninguna rótula su ángulo máximo. Se ilustra en la Imagen [ 51].

Imagen 51 - Volumen de trabajo

Una particularidad geométrica de los robots delta es que su volumen de trabajo no es convexo . Es decir, los dos extremos de una recta pueden ser alcanzables individualmente y, sin embargo, un
punto intermedio de esa misma recta no serlo.

Modelo Matemático

E l movimiento lineal (movL ) consiste en que el efector realice una trayectoria recta en el espacio cartesiano. Para conseguirlo, se imagin a una recta entre el punto de inicio y el de destino , se parte en tramos cortos, y se resuelve la cinemática inversa en cada punto intermedio. Dentro de cada tramo el movimiento sigue siendo una recta en el espacio articular (movJ ), pero si los tramos son suficientemente cortos, el recorrido del efector se termina asimilando a una recta.

El tramo no puede achicarse indefinidamente , los motores necesitan una distancia mínima para frenar. Es to representa una limitación estructural del método.

Antes de ejecutar cualquier movimiento en línea recta | (movL) , se valida cada punto intermedio
planificado; si alguno resulta inalcanzable, el movimiento se rechaza por completo antes de | arrancar.

Igualmente, el movimiento lineal se reservó para el modo Teach, en el que el volumen de trabajo se encuentra reducido a límites donde se conoce que son siempre alcanzables, y sus trayectorias lineales

8.6. P erfiles de movimient | o
Utilizar una rampa trapezoidal | le permitió al robot reducir el estrés mecánico que genera un
inicio y parada bruscos. También garantiza que los motores | no pierdan pasos al pasar de reposo a su
velocidad de régimen . Se ilustra en la Figura [8].

Su funcionamiento es el siguiente, se aumenta la velocidad con una aceleración cons tante hasta llegar a la velocidad de régimen, se sostiene esa velocidad , y luego se reduce en una desaceleración constante de la misma magnitud . Cuando la distancia a recorrer es corta y no se alcanza la velocidad de crucero, el trapecio termina siendo en un perfil triangular, que es el caso habitual en este robot dado el elevado límite de velocidad adoptado .

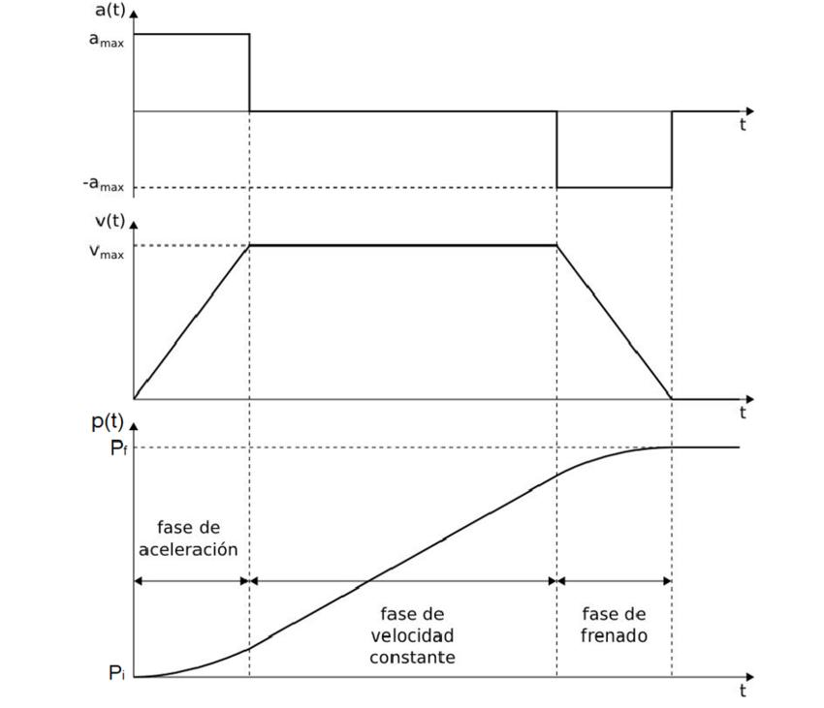
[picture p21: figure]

Figura 8 – Perfil trapezoidal respecto al tiempo

Modelo Matemático

El perfil trapezoidal especifica la velocidad en función del tiempo, pero lo que el firmware controla directamente es el intervalo entre pulsos consecutivos. Para c alcular ese intervalo se utiliza el Algoritmo

c0 = 0,676 √
2
a

Donde c0 es el intervalo inicial, y calcula los siguientes como:

cn+1 = cn −

2 cn
4n + 1

Dentro del programa , la aceleración a es un valor configurable . De esta manera se logra acelerar el sistema, y ajustarlo para conseguir un buen funcionamiento dinámico.

Los tres motores deben arrancar y llegar a destino de manera simultánea aun cuando cada uno deba recorrer una distancia distinta , esto aporta suavidad y control al movimiento.

La sincronización hace que la trayectoria sea una recta en el espacio de los ángulos articulares.

Para lograrlo, se debe escalar la velocidad y la aceleración de cada eje en proporción a su recorrido relativo , respecto del eje que más debe moverse:

ki =

di
max(d1, d2, d3

)

, vi = ki vmax, ai = ki amax

C on este cálculo se definen las aceleraciones y velocidades para que | los tres ejes tard en
exactamente lo mismo en llegar a destino, independientemente de cuánto deba recorrer cada uno | .

Esta propiedad, además de sincronizar los tres motores, es la que permite estimar el tiempo de
un movimiento coordinado a partir únicamente del eje que más recorre , lo que facilita el cálculo de

### 8.7. Intercepción de un objetivo en movimiento

Uno de los compromisos fundamentales de este proyecto era lograr clasificar las piezas que vienen en movimiento, sin detener la cinta. Para lograrlo se debió definir un método que calcule la intercepción entre la trayectoria de la pieza y la del robot , y que asegure el agarre.

Cuando una pieza avanza sobre la cinta a velocidad constante, hay que determinar dónde y
cuándo el brazo debe encontrarla. El problema principal es el siguiente:

Dónde va a estar la pieza en el momento del encuentro depende de cuánto tarda el robot en llegar, y cuánto tarda el robot depende de a dónde tiene que ir.

Modelo Matemático

Se resuelve por iteración de punto fijo . S e parte de una estimación del punto de encuentro, se calcula cuánto tardaría el robot en llegar ahí, se recalcula dónde estaría la pieza para ese instante, y se repite hasta que dos iteraciones sucesivas coincidan dentro de una tolerancia.

La maniobra de agarre se divide en dos tramos. En el primero, el robot se desplaza lo más rápido posible hasta un punto de aproximación, ubicado levemente por encima y por detrás del lugar donde
estará la pieza. En el segundo, desciende sobre ella avanzand | o en el mismo sentido que la cinta.
En búsqueda de un agarre suave, la velocidad y dirección con la que el gripper llega debe | ser
similar a la de la pieza. Esto se consigue | apuntando el tramo final a un punto que sobrepasa levemente
a la pieza, de modo que el gripper cruce la altura de la pieza | todavía en movimiento.
Un dato importante es que el robot es mucho más rápido que la cinta | , la maniobra de agarre
tarda alrededor de 0,4 segundos, mientras que una pieza tarda cerca de 2 segundos en cruzar desde que se la detecta hasta el área de trabajo. Es decir que, si el robot no está ocupado con otras piezas siempre llega antes, por lo que hay que decirle cuándo arrancar el tramo final. Por eso el resultado del cálculo no es solo un punto de encuentro , incluye también el instante exacto en que hay que lanzar ese último tramo, de modo que el contacto ocurra justo cuando la pieza pasa por ahí.

### 8.8. Calibración del modelo contra el robot construido

El modelo geométrico desarrollado en las secciones anteriores describe un robot delta ideal. En las primeras pruebas de posicionamiento se detectó que la punta no llegaba exactamente a las

E xistía una discrepancia entre el modelo y el robot construido. En un robot delta las tolerancias
de fabricación son exigentes, y en un prototipo construido | como proyecto de carrera, pequeñas

La diferencia más notoria apareció en el radio de la base: el modelo 3D indicaba 7,075 cm,
mientras que en el robot construido resultó de 8,275 cm, que es el valor adoptado en la cinemática. Se cree que esto se debe a los soportes de los motores, que tienen dimensiones ligeramente distintas a las

Además, fue necesario compensar un error residual en el plano horizontal mediante dos ganancias, aplicadas a las coordenadas x e y antes de resolver la cinemática inversa:

x ← kx, x, | y ← ky, y, | kx = 1,02, ky = 0,98
Estos valores se obtuvieron | moviendo el robot a posiciones conocidas y midiendo con regla la
posición real de la punta. | Estas ganancias absorben los posibles errores en las longitudes de los
eslabones, las imperfecciones del montaje y el juego de las rótulas. | Se trata de una leve asimetría de la

Un tratamiento más riguroso reemplazaría las dos ganancias por una identificación completa de los parámetros geométricos, pero por cuestiones de tiempo y por el buen resultado que este ajuste

Firmware del Sistema Embebido

### 9.1. Arquitectura del firmware

El firmware corre en un único núcleo del ESP32. Un bucle principal (loop()) se repite
continuamente y, en cada vuelta, actualiza la lectura de los encoders y la máquina de estados del robot. A esto se suman tres interrupciones temporizadas, una por motor, que generan los pulsos que mueven a los motores de forma independiente del loop principal.
Una regla se mantiene en todo el código, y fue un criterio de diseño desde el comienzo | , no usar
la función delay(). Todas las esperas son no bloqueantes | , en cada vuelta del bucle se compara la hora
actual (millis()) con la del inicio de la espera, sin detener nada. Un delay( | ) frenaría al mismo tiempo
la generación de pasos, la lectura de los encoders y la máquina de estados, y con el brazo en movimiento eso significa perder el control del robot .

L a asignación de pines se concentra en un único archivo (Pinout.h), de modo que un cambio de conexionado se corrige en un solo lugar.

Desde el comienzo del desarrollo, el firmware se organizó en módulos independientes, cada uno responsable de una única parte del sistema. La estructura se definió antes de escribir la lógica del robot . Primero se crearon las carpetas y los archivos de cada módulo, vacíos, y a partir de ahí cada subsistema se fue completando por separado. Los módulos se detallan en la Tabla [ 4].

El criterio aportó a la programación en los siguientes aspectos :

- | Permitió agregar funciones sin afectar las que ya funcionaban | : Al incorporarse cada una en su
propio módulo, el código probado no necesitaba modificarse.
- | Simplificó la detección de fallos : Cada subsistema puede verificarse por separado | y, ante un
problema, la búsqueda se acota al módulo involucrado.
- Separó el cálculo del hardware : Los módulos de cinemática e intercepción solo realizan cálculos, sin acceder a motores ni sensores, lo que le brinda robustez .
Carpeta | Responsabilidad | Módulos

hardware/

Manejo directo de cada
componente físico

Motores, encoders, finales de carrera, sistema neumático, cinta

kinematics/ | Geometría y cinemática del robot | Cinemática inversa
motion/ | Planificación de movimientos | Movimiento lineal, intercepción de piezas
robot/ | Coordinación del sistema

Máquina de estados, generación de pasos, supervisión de colisiones, telemetría

Tabla 4 – Módulo del Firmware

Firmware del Sistema Embebido

### 9.2. Máquina de estados del robot

El comportamiento del robot está organizado como una máquina de estados , en cada momento el robot está en un estado, cada estado tiene su propia función y esa función se ejecuta en cada vuelta del bucle mientras el estado está activo. Los estados se agrupan en cuatro conjuntos, marcados por
color y por fila en la Figura [ 9], el C iclo C omún, el recorrido de los modos Color y Forma, el recorrido del modo Box , y los estados de colisión y error. Aparte queda el modo Teach, que suspende el ciclo de clasificación. Antes de evaluar el estado actual, cada vuelta ejecuta primero la supervisión de colisiones , sección «Supervisión de colisiones», que puede interrumpir cualquier estado y llevar al robot a la parada por colisión.

El C iclo Común de clasificación recorre los siguientes estados:

- HOMING: C alibración inicial, en la que el robot busca los finales de carrera y calibra los encoders.
- | GO_HOME_IDLE: | E l robot va hacia la posición de origen (home) y, al llegar, pasa a
WAIT_PIECE.
- | WAIT_PIECE: | E spera quieto en home. Cuando recibe la señal de que una pieza alcanzable
cruzó la línea de detección, empieza a buscarla.
- | PICK_APPROACH: | Se acerca al punto de espera sobre la pieza, a máxima aceleración.
- | PICK_DESCEND: | B aja y agarra la pieza, a aceleración mínima, entrando a favor del
movimiento de la cinta según la intercepción calculada (sección «Intercepción de un objetivo en movimiento»).
- | PICK_LIFT: | L evanta la pieza.

A partir de ahí, el recorrido depende del modo de clasificación activo.

Modos Color y Forma:

- | BIN_SETTLE: | Queda quieto un instante para que la pieza caiga derecha.
- | RELEASE_WAIT: | A paga la bomba y espera a que la pieza se despegue.

Modo Box:

- | BOX_TRANSIT: | C ruza por encima de la caja.
- | BIN_SETTLE y RELEASE_WAIT: | L os mismos estados que en los otros modos, para soltar

Firmware del Sistema Embebido

Al terminar de entregar la pieza, el robot revisa la cola | , si hay otra pieza pendiente, va
directamente a buscarla, sin pasar por home; si no hay ninguna, va hacia home y queda esperando en

Hay además tres estados fuera del ciclo normal. Ante una colisión, el robot pasa a
COLLISION_STOP , frena, suelta la pieza y detiene la cinta, para que no lleguen más piezas mientras se recalibra. Luego vuelve a HOMING conservando las piezas pendientes y, al terminar, la cinta arranca
de nuevo y el robot retoma el trabajo. El estado ERROR se alcanza cua | ndo los finales de carrera no
aparecen durante el homing, cuando hay tres colisiones seguidas o por una parada manual, y el robot queda detenido hasta que el operador lo reinicia.

Por último, el Modo TEACH , descripto en la sección «Modo Teach», se ingresa únicamente desde WAIT_PIECE, con el brazo ya quieto en la posición de home.

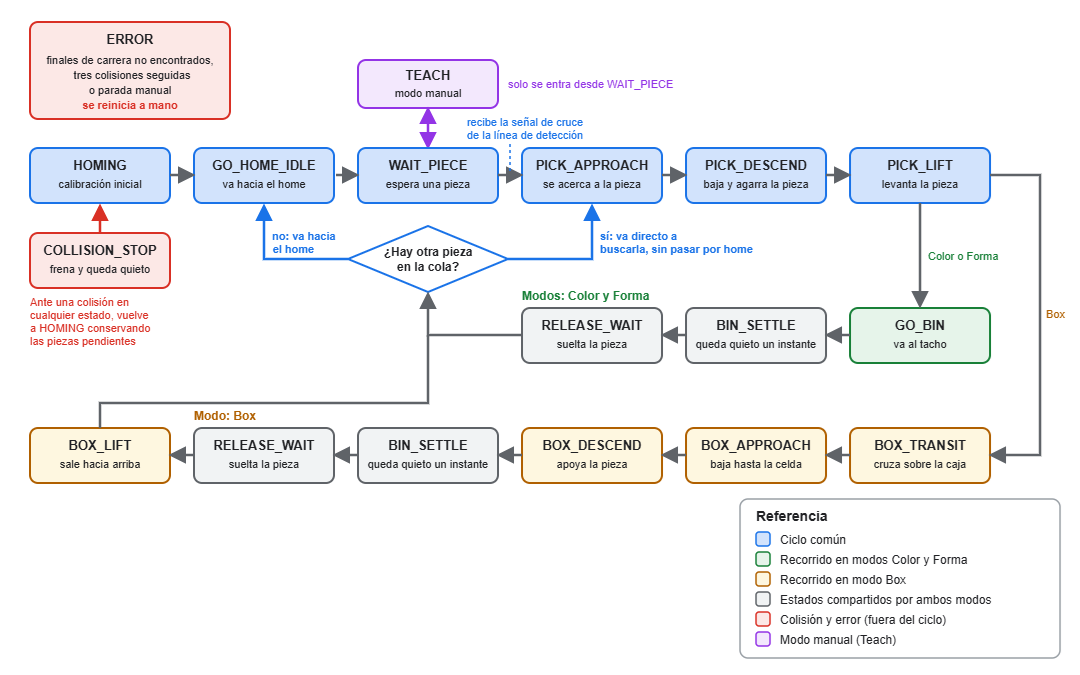
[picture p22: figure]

Figura 9 – Máquina de estado del robot.

### 9.3. Generación de pasos y rampa trapezoidal

Los pulsos de cada motor los genera un temporizador de hardware del ESP32, uno por motor,
que funciona en paralelo con el programa principal. Cada temporizador se dispara cada 20
microsegundos y, en cada disparo, decide si ya toca dar un paso. Cuando toca, genera el pulso y calcula cuánto esperar hasta el siguiente: cuanto más corta es la espera, más rápido gira el motor. Ese cálculo sigue el algoritmo de Austin , sección «Algoritmo de Austin», pensado para generar perfiles trapezoidales sección «Rampa trapezoidal ».

Firmware del Sistema Embebido

### 9.4. Supervisión de colisiones

La supervisión de colisiones no es | un control de posición , el robot mueve los motores | a lazo
abierto, contando micropasos , se describe en la sección «Conversión de ángulo a micropasos», y los encoders no corrigen nada. Lo que hacen es vigilar. En cada vuelta del bucle se comparan, para cada motor, dos medidas , cuánto giró según el encoder y cuánto se le ordenó girar según los pasos enviados.

Como se comparan cambios y no ángulos absolutos, la supervisión no depende de la calibración exacta del encoder. Si la diferencia entre las dos es grande y se mantiene, se declara una colisión.

El límite de diferencia permitida es | dinámico. La medición del encoder llega siempre atrasada
respecto de los pasos, y ese atraso produce una diferencia que crece con la velocida | d. Un límite fijo lo
bastante alto para tolerarla no detectaría nada con el robot quieto o lento. Por eso el límite combina
una parte fija con un margen que crece con la velocidad.

Con el robot quieto en home, la supervisión hace además otros dos chequeos . El primero controla que el encoder siga marcando mientras el brazo espera. El segundo compara lo que marca el encoder cada vez que el brazo vuelve a home . Es un tipo de falla distinto, una descalibración y no un golpe,

Ante una colisión confirmada, el robot frena los tres motores, suelta la pieza, detiene la cinta,
espera unos segundos y vuelve a hacer el homing conservando las piezas | pendientes, sección «Máquina
de estados del robot». Si ocurren tres colisiones seguidas sin completar una pieza | , pasa al estado de
error y espera la intervención del operador, porque el problema requiere una revisión física del robot.

### 9.5. Telemetría, parámetros y registro de fallos

El firmware informa lo que está pasando mediante tres líneas de telemetría, sección «Protocolo de comunicación», y permite ajustar un conjunto de parámetros sin recompilar ni volver a cargar el programa. Por ejemplo, se pueden ajustar los umbrales de la supervisión de colisiones, límites de velocidad y aceleración, ángulos de homing, entre otros. Los ajustes se pueden guardar en la placa, de

El firmware tampoco lleva un historial a lo largo del tiempo. Solo conserva los últimos fallos y los contadores. Esto fue una decisión de diseño, para no sobrecargar al firmware y que pueda dedicarse a lo que necesita realizar en tiempo real, sección «Reparto de responsabilidades». Es la PC la que está recibiendo toda la telemetría, y construyendo ese historial, que se muestra en la pestaña de Rendimiento, sección «Pestaña de Rendimiento».

Firmware del Sistema Embebido

### 9.6. Modo Teach

El modo Teach es un modo aparte del ciclo de clasificación , permite al operador manejar el brazo a mano desde la interfaz, grabar secuencias de movimiento y reproducirlas después. Se entra únicamente
desde WAIT_PIECE, con el robot ya quieto en la posición de home | , ahí la posición de partida es
conocida sin que el firmware necesite resolver la cinemática directa, que no está implementada de su lado, sección «Reparto de responsabilidades». La pantalla desde la que se maneja se describe en la sección «Pestañas de Teach».

El control manual funciona con un mecanismo de seguridad tipo hombre muerto , el brazo solo se mueve mientras el operador mantiene apretado el control (tecla o joystick). La interfaz no envía un destino sino una dirección de movimiento, que repite continuamente; el firmware la considera vigente por 350 milisegundos y, si no recibe una nueva, la descarta y el brazo se detiene. Así, si el operador suelta el control o la interfaz deja de responder, el brazo termina el tramo que tiene en curso y se detiene, en lugar de seguir moviéndose sin control.

### 9.7. Protocolo con la aplicación de PC

La aplicación de PC | también está dividida en módulos | . Un único p | rograma de entrada
(kuko_app.py) pone en marcha el enlace serie, la visión y la interfaz | .

La manera en la que el firmware se conecta con la aplicación e stá escrita en un único documento (PROTOCOLO.md), que funciona como referencia . Si el firmware y la aplicación no coinciden, el que se apartó del documento es el que debe corregirse.

Sistema de Visión Artificial

### 10.1. Funcionamiento de la cámara

El procesamiento de imagen corre íntegramente del lado de la PC, sobre OpenCV, una biblioteca
de código abierto para visión por computadora. El enfoque elegido es de visión clásica, | es decir, separar
el color, encontrar los contornos | y medir la forma , esto se resuelve con | fórmulas matemática s
programadas, y no con una red neuronal entrenada con ejemplos. Esto lo hace determinístico , la misma imagen produce siempre la misma detección, sin depender de un entrenamiento previo; si una pieza no se detecta, es porque no cumple con la condición matemática que determina su detección.

La cámara se supervisa de forma automática, para que se recupere sola si se desconecta. Esto surgió de un problema que tuvimos con el extensor USB que usábamos para conectarla a la computadora, era de mala calidad y hacía falso contacto, y cada vez que se desconectaba había que reiniciar el programa para recuperar la imagen, lo que no era práctico.

Para resolverlo, cambiamos el extensor USB por uno de mejor calidad y programamos una lógica
de control de la cámara. El sistema almacena la hora de cada imagen que llega y, si pasan más de 2 segundos sin recibir una nueva, la considera desconectada, la cierra y la vuelve a abrir. Reintenta cada
3 segundos y, si la cámara sigue sin aparecer, el intervalo se va duplicando hasta llegar a un m | áximo
de 20 segundos. Cuando la cámara vuelve, el sistema retoma el trabajo solo, sin reiniciar nada.

Este sistema se visualiza en la Figura [10].

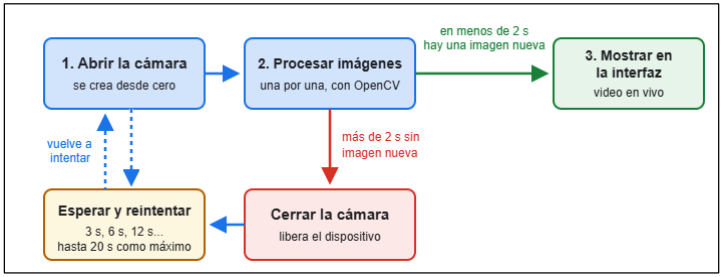
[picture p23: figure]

Figura 10 - Recorrido de la imagen y recuperación ante una desconexión.

### 10.2. Detección por color en HSV

Para detectar el color de una pieza, primero hay que decidir cómo describirlo. Los dos espacios
de color más usados son RGB y HSV | , cuya distribución se visualiza en la | Figura [11].
En RGB (Red [rojo], Green [verde], Blue [azul]) un color se describe por | su proporción de rojo,
verde y azul, y se representa como un cubo. En HSV (Hue [tono], Saturation [saturación], Value | [valor])
se describe por su tono (el color en sí, como rojo o azul), su saturación (qué tan intenso es) y su valor
(qué tan claro u oscuro es), y se representa como un cilindro.

Sistema de Visión Artificial

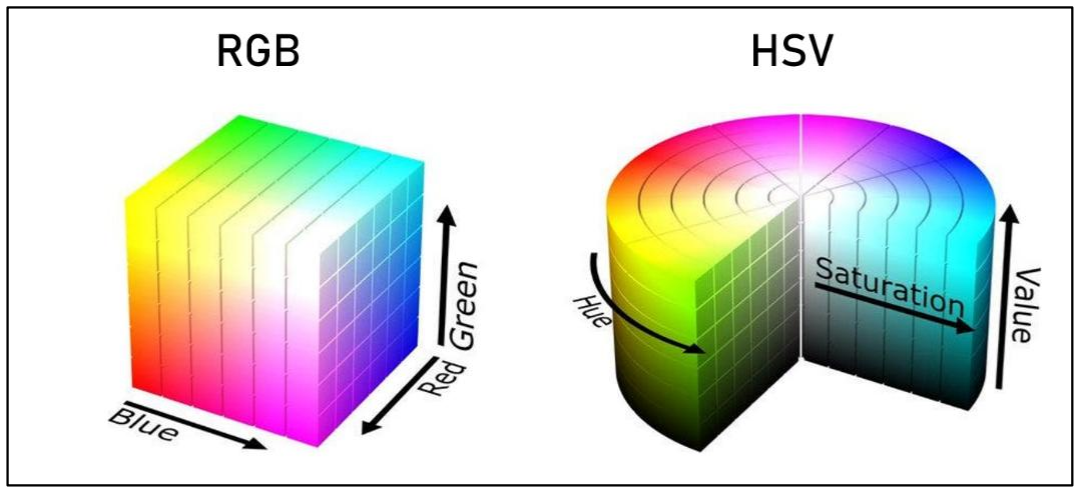
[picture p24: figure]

Figura 11 - Colores RGB y HSV | .
El sistema detecta las piezas en | HSV porque es el que mejor resiste los cambios de iluminación.
En RGB, un cambio de luz modifica las tres componentes a la vez, y un mismo color deja de ocupar
una zona compacta del espacio. Por ejemplo, una pieza roja bajo luz normal podría medir RGB | ≈ (220,
30, 25) y, en una zona más oscura de la cinta, RGB | ≈ (90, 12, 10) , dos puntos muy alejados entre s í,
aunque el color sea el mismo , Figura [12].

En HSV, en cambio, el color se concentra en una sola componente, el Tono, y separa la Saturación del Valor. Volviendo al ejemplo anterior de la pieza roja, e sas dos mediciones para HSV devuelven la misma Saturación y un Tono casi idéntico ( ≈ 1° contra ≈ 2°); solo cambian en el Valor ( ≈ 86% contra ≈ 35%). Por eso, aunque cambie la luz, si el color de la pieza se encuentra dentro del rango configurado, la pieza se sigue detectando , Figura [12].

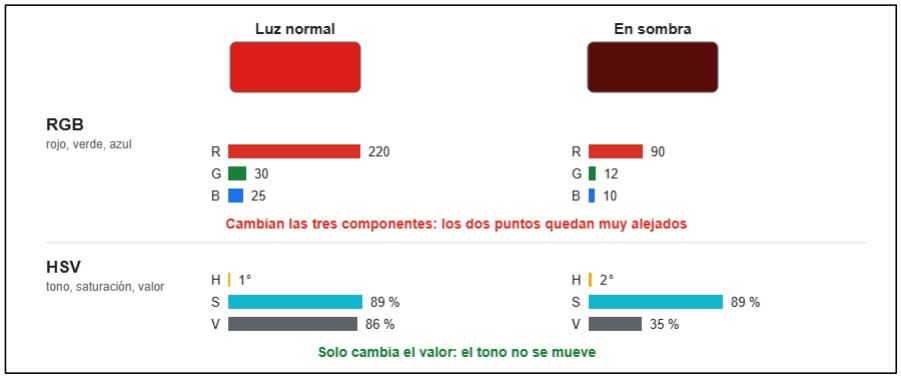
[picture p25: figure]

Figura 12 - La misma pieza roja, con luz normal y en sombra

### 10.3. Detección y clasificación por forma

Cada pieza detectada se clasifica en cuadrado, hexágono o círculo , la diferencia entre estas se pueden calcular mediante dos condiciones geométricas sobre su contorno. Se ilustra en la Figura [13].

La primera es la redondez, que se mide con la circularidad. Es un valor que se calcula comparando el área de la pieza con su perímetro, y que da 1 para un círculo perfecto y menos para cualquier otra figura. Gracias a est o se reconocen los círculos, que es la figura con valor cercano a 1 de redondez.

Sistema de Visión Artificial

El segundo parámetro a considerar es el número de vértices , el contorno de una pieza detectada está formado por muchísimos puntos, así que se lo simplifica reemplazándolo por un polígono con la menor cantidad de puntos posible, que conserve su forma. Los puntos que quedan son las esquinas de la pieza, y contarlas pe rmite distinguir un cuadrado (4) de un hexágono (6).

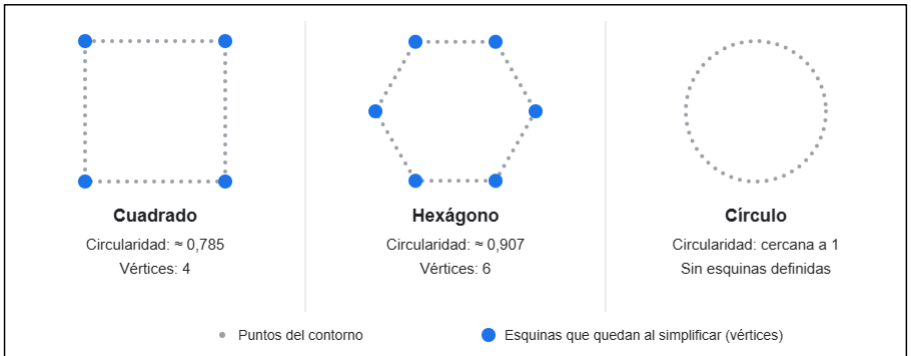
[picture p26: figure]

Figura 13 - Circularidad y vértices

### 10.4. Separación de piezas en contacto

Cuando dos piezas del mismo color se tocan sobre la cinta, el sistema las ve como una única silueta y no podría clasificarlas ; Figura [14], panel 1. Para separarlas se sigue este procedimiento.

Primero se busca el centro de cada pieza. Para eso, OpenCV calcula, para cada punto de la silueta, su distancia al borde más cercano. En el centro de una pieza esa distancia es máxima, mientras que, en la zona de contacto, que es fina, es baja ; Figura [14], panel 2 ; donde los tonos más oscuros indican mayor distancia al borde. Cada punto de máxima distancia es el centro de una pieza, y por lo tanto la cantidad de centros encontrados indica cuántas piezas hay.

Luego, cada punto de la silueta se asigna al centro que tiene más cerca, con lo que la silueta se corta por la mitad entre los centros, justo en la zona de contacto ; Figura [14], panel 3. Cada pieza resultante se clasifica por separado, según su color y su forma.

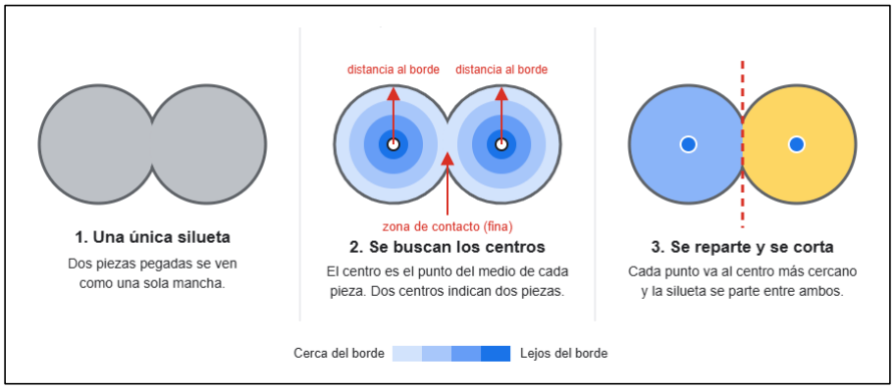
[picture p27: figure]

Figura 14 - Separación de piezas en contacto .

Sistema de Visión Artificial

### 10.5. Procesamiento de imágenes

La cámara capta un campo mucho más amplio que la cinta. Cada fotograma se gira 90°, para
que la cinta se vea horizontal, y se recorta hasta dejar únicamente la zona útil , se descarta cualquier sector donde nunca aparecen piezas. El recorte conserva la resolución original, por lo que no se pierde detalle, y reduce la cantidad de píxeles que se procesan en cada fotograma.

Para saber que una pieza que aparece en un fotograma es la misma que se vio en el anterior, el programa la sigue cuadro a cuadro. En la imagen hay una línea fija de detección: cuando una pieza la cruza, el programa registra el evento una única vez, y ese e vento es el que da aviso al robot para iniciar

La línea se marcó sobre la cinta a 23 cm del centro del robot. La línea dibujada en la imagen se ajustó luego hasta hacerla coincidir con esa marca.

La posición de la pieza se mide en píxeles, mientras que el robot trabaja en centímetros dentro

La conversión se basa en cuatro medidas tomadas con regla sobre la cinta: el largo de cinta que abarca la imagen (21,5 cm), su ancho (14 cm), la posición de la línea de detección respecto del robot
(X = −23 cm) y la del borde inferior de la imagen (Y = −1, | 95 cm). Las dos primeras dan la escala | ,
las otras dos funcionan como puntos de referencia.
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

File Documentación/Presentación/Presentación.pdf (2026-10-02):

## Universidad Nacional de Lomas de Zamora

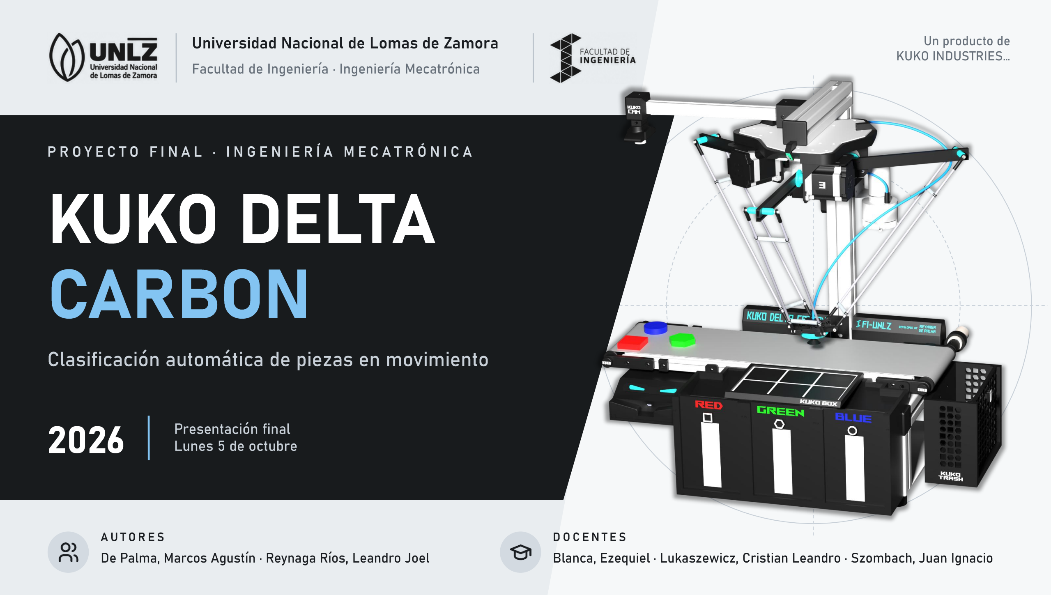
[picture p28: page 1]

Facultad de Ingeniería · Ingeniería Mecatrónica

Un producto de
KUKO INDUSTRIES…

### PROYECTO FINAL · INGENIERÍA MECATRÓNICA

# KUKO DELTA CARBON

## Clasificación automática de piezas en movimiento

### 2026 Presentación final Lunes 5 de octubre

AUTORES
De Palma, Marcos Agustín · Reynaga Ríos, Leandro Joel

DOCENTES
Blanca, Ezequiel · Lukaszewicz, Cristian Leandro · Szombach, Juan Ignacio

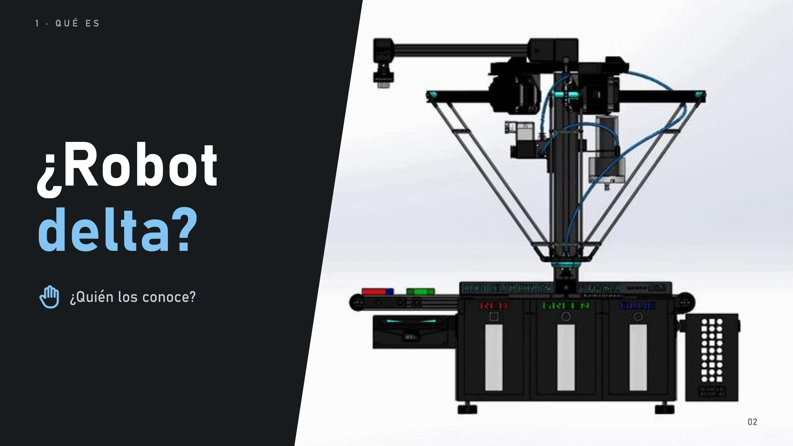
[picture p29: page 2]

1 · QUÉ ES

# ¿Robot delta?

## ¿Quién los conoce?

1 · QUÉ ES

## Manual · Repetitivo

?

## Rápido · Sin frenar la cinta


### La cinta no se detiene

# ¿Qué es un robot delta?

1 · QUÉ ES

### SERIE

# Brazo

## Hombro · Codo · Muñeca

### PARALELO

## Araña Motores fijos · Brazos livianos

# KUKO Delta Carbon


1 · QUÉ ES

PICK & PLACE

# Ver

# Anticipar

# Atrapar

# Clasificar

# Lo que sabe hacer


1 · QUÉ ES

Clasificación por Color | Clasificación por Forma
Box | Teach

2 · CÓMO FUNCIONA

Computadora; Visión · Interfaz; Microcontrolador; Tiempo Real; Actuadores y sensores; Motores · Cinta · Neumática · Sensores; USB Serie; Diagrama eléctrico

# El cuerpo


ROBOT REAL | MODELO 3D

# Modelo 3D = Robot real

## Primero se diseñó todo en 3D

# Materiales

# Aluminio

### Perfiles · Cuerpo rígido

# Impresión 3D

### Piezas de diseño propio

# Fibra de carbono

### Paralelogramo articulado

# Cómo se conecta

Potencia · Control · Sensado | Energía | Señal

Fuente 48 V; Drivers ×3; Motores ×3; Encoders ×3; Fuente ATX; Microcontrolador; Finales de; carrera; Bomba + válvula; Cinta; Ángulo; Pulso + Dirección

# La visión

# Color

### HSV: El tono no cambia con la luz

# Forma

### Circularidad · Vértices Piezas pegadas


# Posición

### Línea de detección 23 cm antes del robot

Área de trabajo; Detección; Robot

23 cm
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

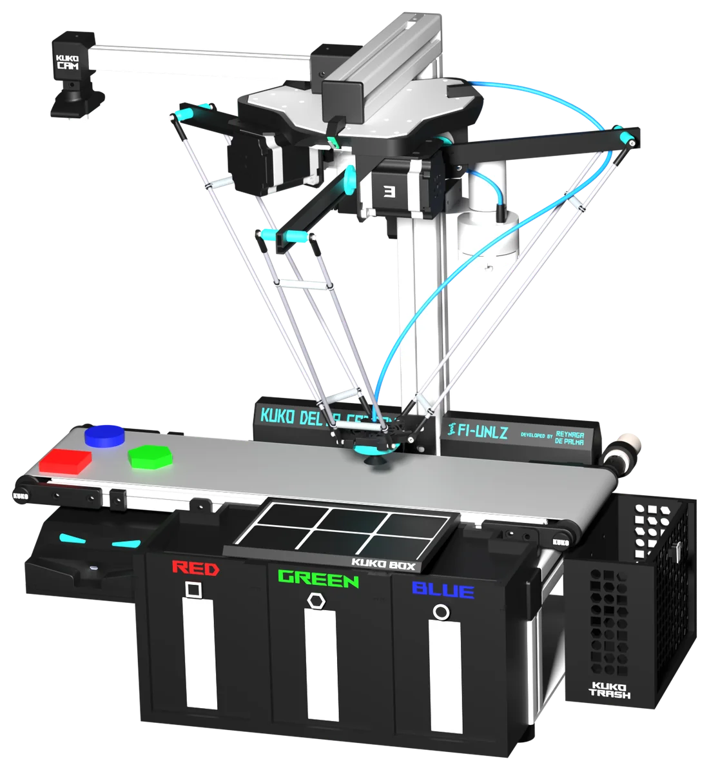
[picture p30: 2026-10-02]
Multimedia/KUKO_AR/Kuko_Delta_Carbon_Reynaga_De_Palma_poster.webp

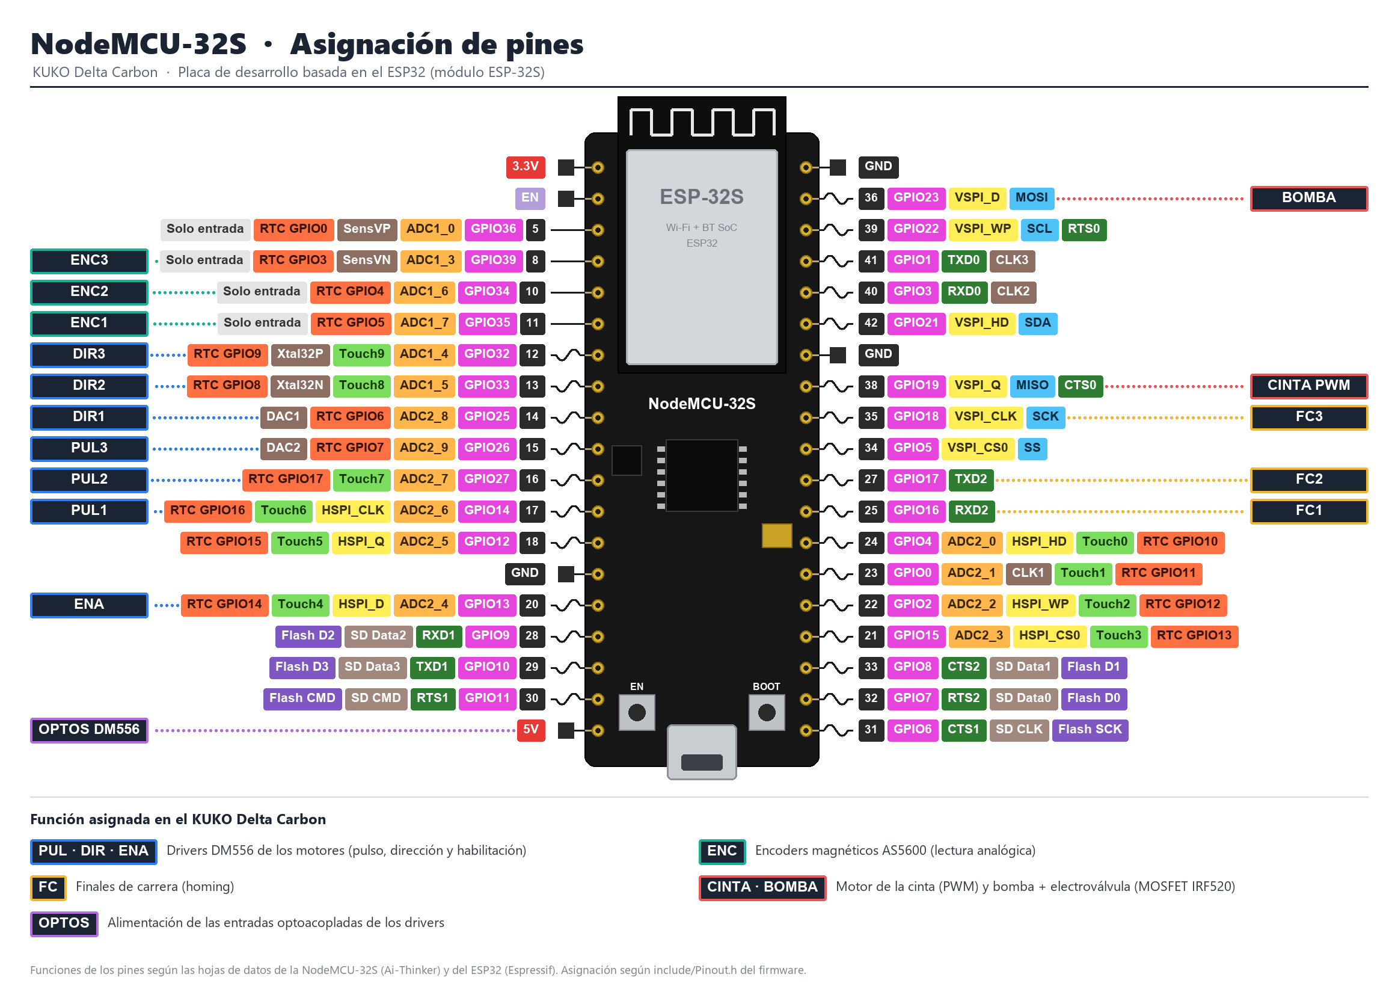
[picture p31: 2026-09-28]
Multimedia/08_Pinout.jpg

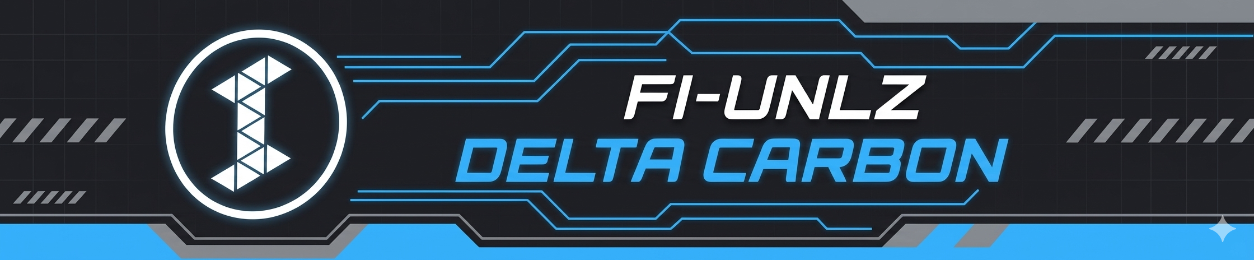
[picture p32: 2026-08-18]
Código/KUKO_DELTA_CARBON/pc/assets/portada.png

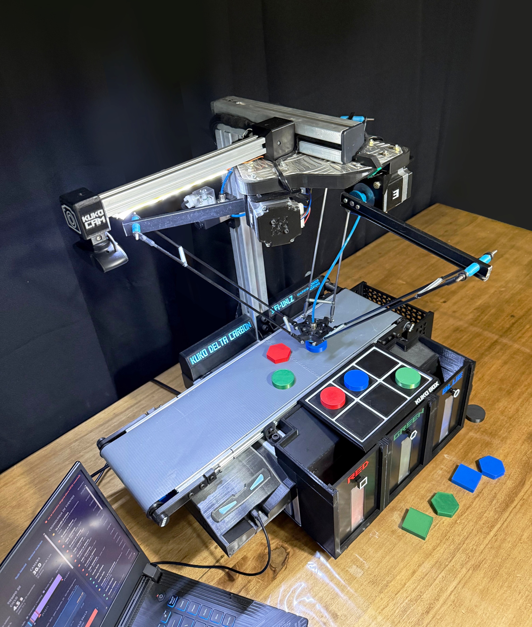
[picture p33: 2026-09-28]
Multimedia/02_Robot_completo.jpg

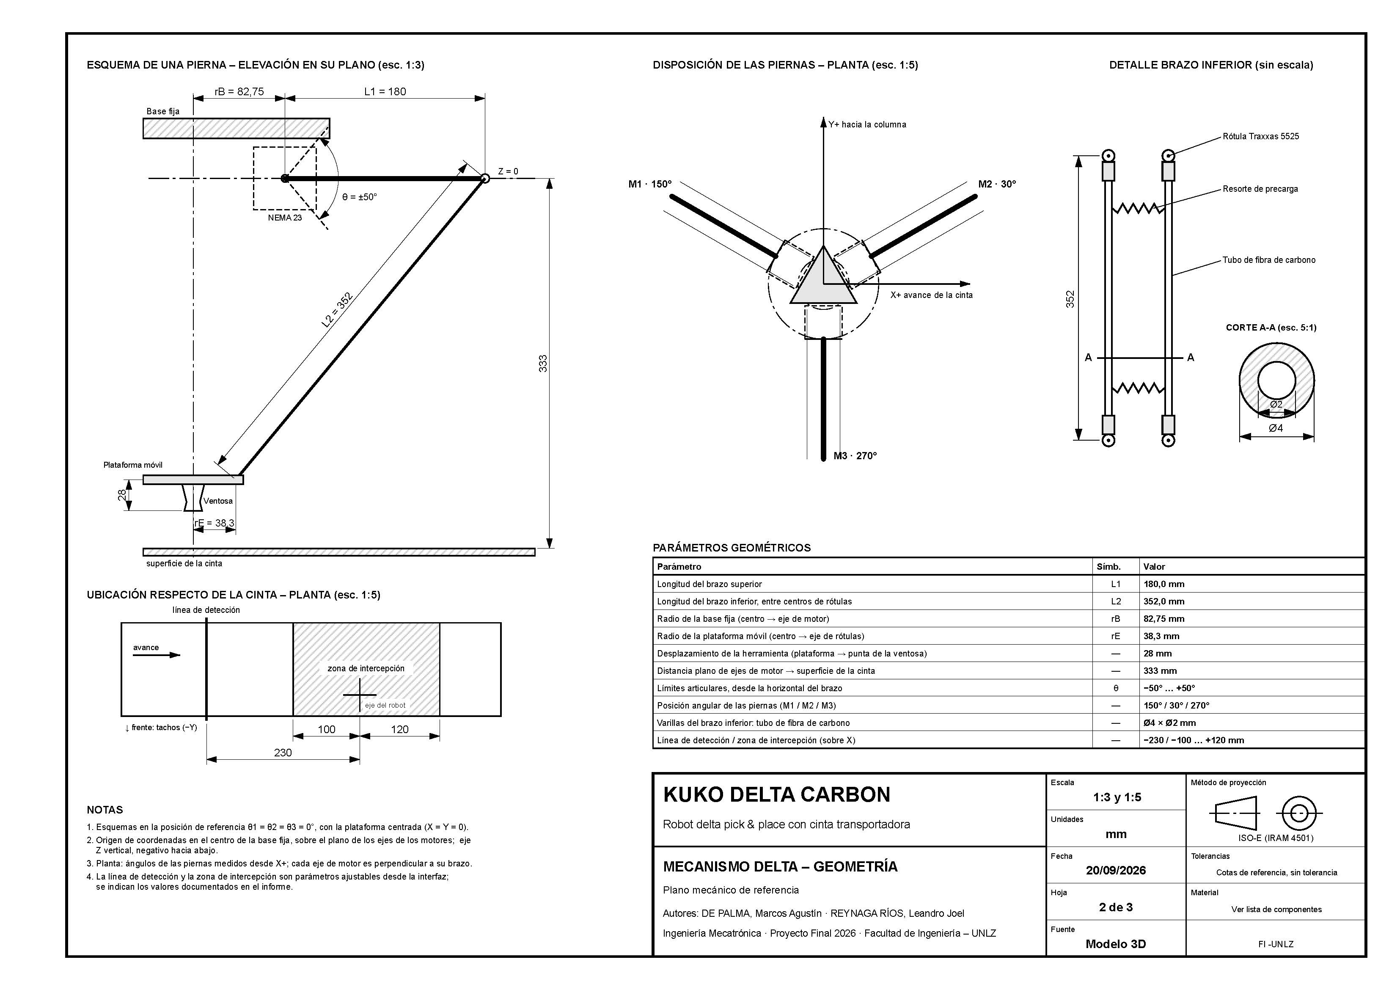
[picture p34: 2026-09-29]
Planos/Plano mecánico/Plano_mecánico_Página_2.jpg

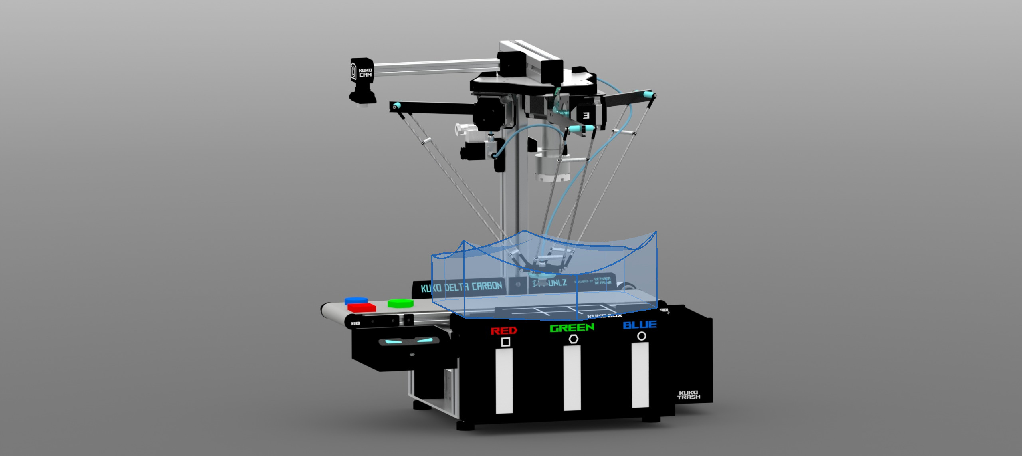
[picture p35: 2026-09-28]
Multimedia/07_Vol_de_trabajo.jpg

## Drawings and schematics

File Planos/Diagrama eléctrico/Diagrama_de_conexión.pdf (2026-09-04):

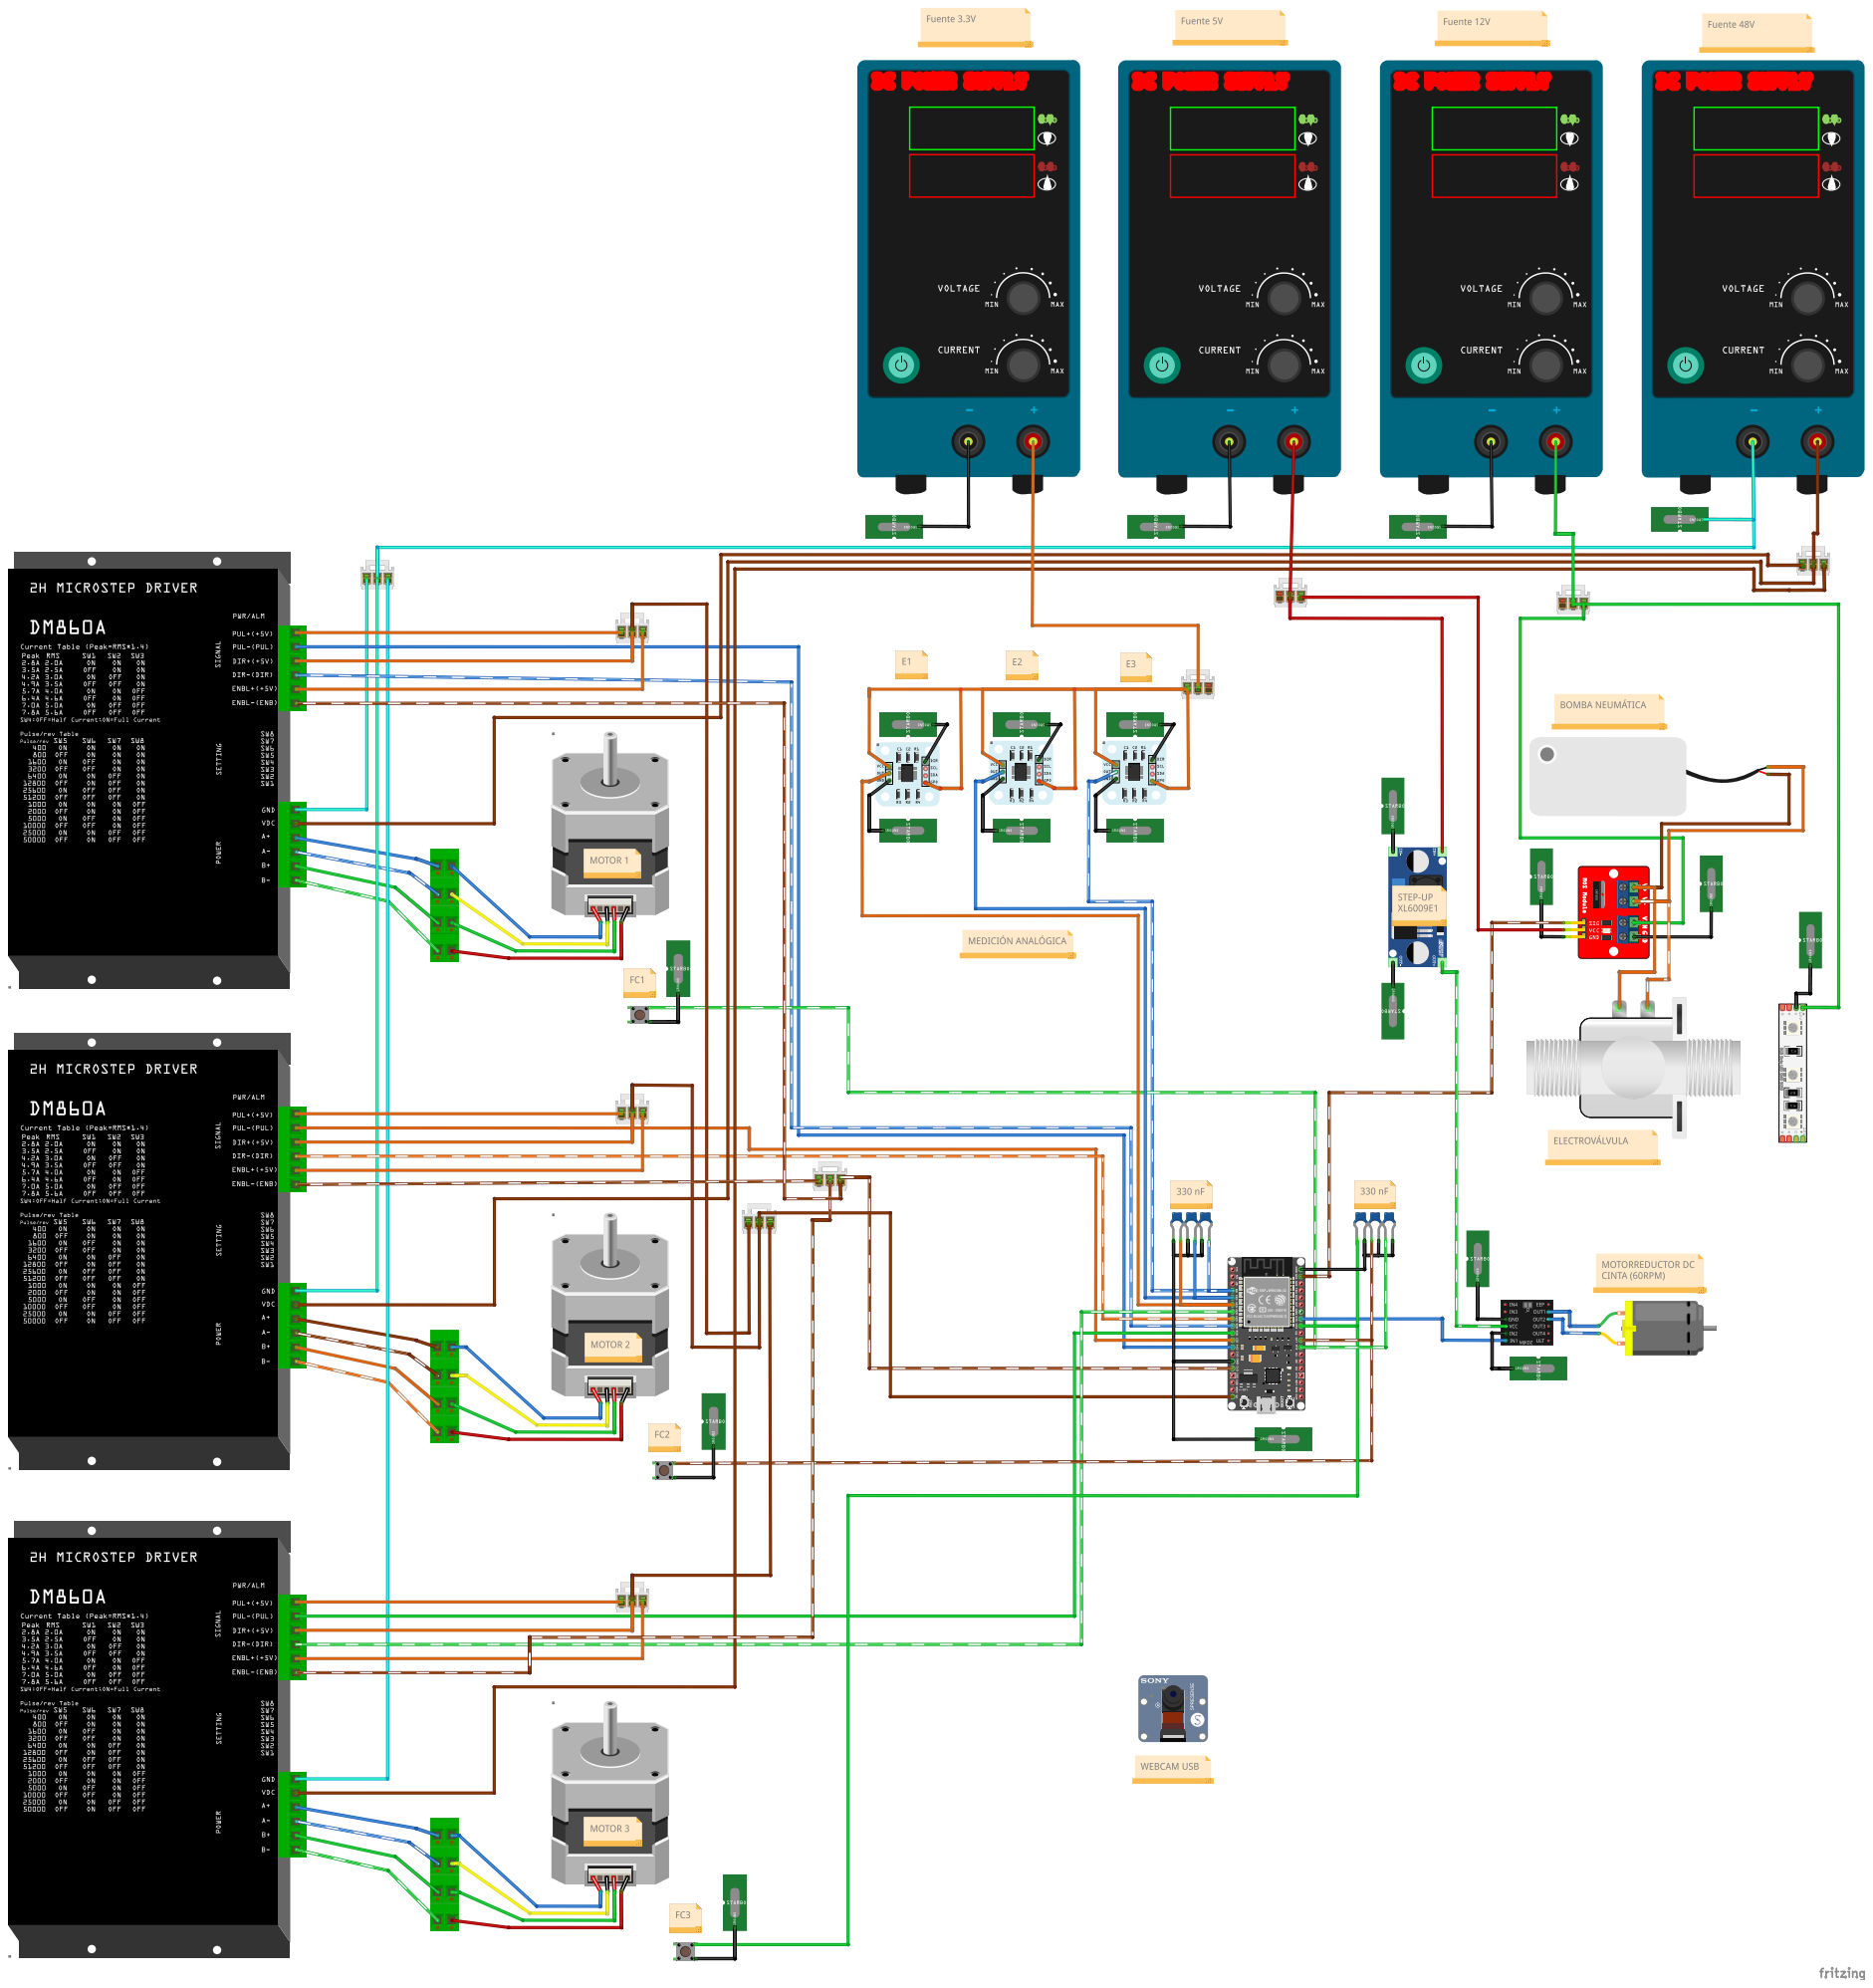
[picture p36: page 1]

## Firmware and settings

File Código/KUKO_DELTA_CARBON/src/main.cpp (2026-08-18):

#include <Arduino.h>
#include "Pinout.h"
#include "hardware/Conveyor.h"
#include "hardware/Encoders.h"
#include "hardware/Pneumatics.h"
#include "hardware/Endstops.h"
#include "hardware/Motors.h"
#include "robot/Robot.h"
#include "kinematics/DeltaKinematics.h"

Robot robot;
Endstops endstops;

// Impresión de diagnóstico no bloqueante: se muestra a intervalos fijos
// en lugar de en cada vuelta del loop (que sería miles de veces por
// segundo, ilegible y con costo real de tiempo de CPU/UART).
uint32_t ultimoPrint_ms = 0;
const uint32_t INTERVALO_PRINT_MS = 200; // 5 Hz, suficiente para ver la evolución en vivo


void setup()
{
    // Buffer de transmision grande ANTES de abrir el puerto (despues de
    // Serial.begin() no tiene efecto). Sin esto, un mensaje largo -- el
    // volcado de fallos del comando 'D', por ejemplo -- llena la FIFO del
    // UART y Serial.print() BLOQUEA hasta que se vacie: a 115200 baudios,
    // 2 kB son ~180 ms con el loop entero congelado. Y si en ese rato el
    // brazo se estuvo moviendo, el encoder ve un salto enorme entre lectura
    // y lectura, el filtro de plausibilidad lo rechaza por implausible y el
    // canal se cae. Con el buffer en RAM, el mensaje se encola y se
    // transmite por interrupcion mientras el loop sigue girando.
    Serial.setTxBufferSize(2048);
    Serial.begin(115200);

    encoders.begin();
    endstops.begin();
    robot.begin();
    robot.startHoming();
    
}

void loop()
{
    // Debe llamarse SIEMPRE, en cada vuelta del loop: es lo que hace avanzar
    // la máquina de estados no bloqueante de los encoders.
    encoders.update();

    robot.update();

    // Cuenta las vueltas para poder informar el ritmo del loop en la línea
    // de salud. Es el primer síntoma de que algo empezó a bloquear: si las
    // vueltas por segundo se desploman, hay un delay(), un Serial.print()
    // que llenó la FIFO o un encoder reintentando lecturas.
    robot.contarVuelta();

    uint32_t ahora = millis();
    if (ahora - ultimoPrint_ms >= INTERVALO_PRINT_MS)
    {
        ultimoPrint_ms = ahora;

    }

}

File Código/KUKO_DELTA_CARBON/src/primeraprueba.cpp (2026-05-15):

#include <Arduino.h>
#include <AccelStepper.h>

/*
====================================================
CONFIGURACION DE PINES
====================================================
*/

#define PIN_ENA   13
#define PIN_STEP  14
#define PIN_DIR   25

/*
====================================================
CONFIGURACION DEL DRIVER
====================================================

Modo DRIVER:
STEP + DIR

AccelStepper::DRIVER
usa:
- 1 pin STEP
- 1 pin DIR
*/

AccelStepper motor(AccelStepper::DRIVER, PIN_STEP, PIN_DIR);

/*
====================================================
VARIABLES DE CONTROL
====================================================
*/

// Velocidad maxima [steps/s]
float velocidadMaxima = 800.0;

// Aceleracion [steps/s²]
float aceleracion = 400.0;

// Movimiento objetivo
long posicionObjetivo = 4000;

// Sentido
bool sentidoHorario = true;

/*
====================================================
SETUP
====================================================
*/

void setup()
{
    Serial.begin(115200);

    /*
    --------------------------------------------
    CONFIGURACION DE PINES
    --------------------------------------------
    */

    pinMode(PIN_ENA, OUTPUT);

    /*
    ENABLE DEL DRIVER
    --------------------------------------------
    En muchos DM556:
    LOW = habilitado
    HIGH = deshabilitado
    */

    //digitalWrite(PIN_ENA, LOW);
    digitalWrite(PIN_ENA, HIGH);
    /*
    --------------------------------------------
    CONFIGURACION DEL MOTOR
    --------------------------------------------
    */

    motor.setMaxSpeed(velocidadMaxima);

    motor.setAcceleration(aceleracion);

    /*
    --------------------------------------------
    PRIMER MOVIMIENTO
    --------------------------------------------
    */

    if(sentidoHorario)
    {
        motor.moveTo(posicionObjetivo);
    }
    else
    {
        motor.moveTo(-posicionObjetivo);
    }

    Serial.println("Sistema iniciado");
}

/*
====================================================
LOOP PRINCIPAL
====================================================
*/

void loop()
{
    /*
    run()
    --------------------------------------------
    Debe ejecutarse SIEMPRE.
    Genera los pulsos STEP.
    */

    motor.run();

    /*
    --------------------------------------------
    CUANDO LLEGA AL DESTINO
    invierte sentido
    --------------------------------------------
    */

    if(motor.distanceToGo() == 0)
    {
        delay(1000);

        posicionObjetivo = -posicionObjetivo;

        motor.moveTo(posicionObjetivo);

        Serial.print("Nueva posicion objetivo: ");
        Serial.println(posicionObjetivo);
    }
}

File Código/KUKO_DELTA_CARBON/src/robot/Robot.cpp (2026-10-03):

#include "Robot.h"
#include "Pinout.h"
#include "hardware/Pneumatics.h"
#include "hardware/Conveyor.h"
#include "hardware/Encoders.h"
#include "kinematics/DeltaKinematics.h"
#include "motion/ConveyorIntercept.h"

#include <string.h>
#include <ctype.h>
#include <stdlib.h>

Conveyor conveyor(CINTAPWM);
Pneumatics pneumatics;

// ============================================================
//  CINTA TRANSPORTADORA
//  v = pi * d * (N/60), con d = 2,4 cm y N = 60 rpm  ->  7,54 cm/s
//  Se toma como constante y conocida: toda la intercepcion depende de este
//  numero, asi que si se cambia la polea o las rpm hay que recalcularlo
//  aca (y recalibrar el PWM de Conveyor::begin(), que hoy arranca al 60%
//  sin relacion medida con las rpm reales).
// ============================================================
static float BELT_VELOCITY_CMS = 4.50f; //antes 7.54, 6.75, 7.2, 7.1 y 7.25

// Cuanto se le manda al driver de la cinta, en porcentaje del PWM. OJO:
// esto NO cambia solo a BELT_VELOCITY_CMS, que es la velocidad MEDIDA y es
// la que usa la planificacion. Tocar uno sin el otro hace que el robot le
// erre a todas las piezas, asi que despues de mover el PWM hay que volver a
// medir la cinta y actualizar el otro numero (la interfaz muestra los dos
// juntos y la vision mide el real, para poder compararlos).
static float CONVEYOR_PWM = 40.0f; // antes 60
static float DETECTION_LINE_X  = -23.0f; // donde la camara detecta las piezas

// Ancho util de la cinta (Y). Fuera de esto el dato de vision es erroneo.
static const float BELT_MIN_Y = -1.95f;
static const float BELT_MAX_Y = 12.05f;

// ============================================================
//  CALIBRACION EN Y DE LA VISION
// ============================================================
// Cuanto se corre en Y la posicion que informa la camara. Es el gemelo de
// VISION_LATENCY_S para el otro eje: aquella corrige el atraso a lo LARGO
// de la cinta (X), esta corrige el error de encuadre a lo ANCHO (Y).
//
// Existe porque el mapa pixel->cm de la vision se apoya en donde cae el
// borde inferior del recorte en coordenadas del robot
// (IMAGE_BOTTOM_Y_CM en config.py), y ese numero se mueve cada vez que se
// toca la camara o se vuelve a armar la cinta. Sin este parametro hay dos
// formas de compensarlo y las dos son peores:
//
//   * correr la ventana de recorte desde la interfaz -- pero el recorte
//     tambien es lo que decide que pedazo de cinta se ve, asi que
//     centrar el agarre desencuadra la imagen y deja media cinta afuera;
//   * editar IMAGE_BOTTOM_Y_CM a mano -- hay que reiniciar el programa, y
//     ademas tiene su par en BELT_MIN_Y/BELT_MAX_Y de aca arriba, que
//     habria que mover junto o el firmware empieza a rechazar piezas de un
//     borde de la cinta por creerlas fuera de rango.
//
// PARA CALIBRARLO: mirar cuanto le erra el gripper en Y (el eje transversal
// a la cinta) y corregir esa cantidad en cm. El brazo va a donde dice la Y
// corregida, y la Y crece hacia el BORDE SUPERIOR de la imagen de la camara
// (ver coordinates.py: el eje de la vision esta invertido respecto del de
// OpenCV justamente para que coincida con el del robot), asi que:
//
//   subirlo  -> el agarre se corre hacia arriba en la imagen
//   bajarlo  -> el agarre se corre hacia abajo
//
// Se suma ANTES de validar contra BELT_MIN_Y/BELT_MAX_Y, no despues: el
// valor corregido es la mejor estimacion de donde esta la pieza de verdad,
// asi que es el que tiene sentido comparar contra el ancho de la cinta.
static float VISION_DY = 0.0f;

// ============================================================
//  LATENCIA DE LA VISION
// ============================================================
// Entre el instante en que la pieza cruza FISICAMENTE la linea de
// deteccion y el instante en que el mensaje llega al ESP32 pasa un
// tiempo muerto: exposicion de la camara, buffer del driver, el
// fotograma que hay que esperar para ver el cruce, la deteccion en
// si y el envio por Serial. Durante todo eso la pieza SIGUE
// AVANZANDO sobre la cinta.
//
// Sin compensarlo, el robot cree que la pieza esta mas atras de
// donde realmente esta, apunta detras de ella, y la pieza le queda
// adelantada: aparece a la derecha de la ventosa.
//
// Se modela como TIEMPO y no como una distancia fija a proposito.
// El error en cm es latencia * velocidad de cinta, asi que
// expresarlo en segundos lo deja valido aunque se cambien las rpm
// de la cinta; una constante en cm habria que recalibrarla.
//
// PARA CALIBRARLO: medir cuanto le erra el gripper en X y dividir
// por la velocidad de la cinta.
//
//     latencia_s = error_cm / BELT_VELOCITY_CMS
//
//   pieza ADELANTADA (a la derecha de la ventosa) -> falta, subirlo
//   pieza ATRASADA   (a la izquierda)             -> sobra, bajarlo
//
// Valor actual: 0,580 s, ajustado contra el robot hasta que el gripper
// dejo de errarle en X (antes 0,199 calculado, un rato en 0, despues
// 0,2554 y 0,2695). Con la cinta a 7,25 cm/s compensa 4,21 cm de avance.
static float VISION_LATENCY_S = 0.580f;
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

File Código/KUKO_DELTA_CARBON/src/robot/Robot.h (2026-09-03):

#ifndef ROBOT_H
#define ROBOT_H

#include <Arduino.h>
#include "Stepper.h"
#include "CollisionGuard.h"
#include "FaultLog.h"
#include "Telemetry.h"
#include "Params.h"
#include "../hardware/Endstops.h"
#include "Pinout.h"
#include "../hardware/Motors.h"
#include "../motion/Trajectory.h"

/**
 * Robot
 * ------
 * Orquestador del ciclo de clasificacion: homing -> esperar pieza ->
 * interceptarla en movimiento sobre la cinta -> dejarla en el tacho que
 * corresponde segun el modo de clasificacion -> siguiente.
 *
 * Todas las esperas son NO BLOQUEANTES (timestamps con millis()). Nunca
 * agregar un delay() en esta clase: congela la generacion de pasos, la
 * lectura de encoders y la maquina de estados entera al mismo tiempo.
 */
class Robot
{
public:

    enum RobotState
    {
        IDLE,
        HOMING,          // busca los finales de carrera y calibra los encoders
        WAIT_PIECE,      // quieto en home, sin piezas alcanzables en la cola
        GO_HOME_IDLE,    // volviendo a home; se interrumpe si aparece una pieza
        PICK_APPROACH,   // tramo 1: accel MAX al punto de aproximacion, y espera ahi
        PICK_DESCEND,    // tramo 2: accel MIN, entra a la pieza a favor de la cinta
        PICK_LIFT,       // tramo 3: accel MAX, despega la pieza de la cinta
        GO_BIN,          // tramo 4: accel MAX hasta el tacho que corresponde
        BIN_SETTLE,      // 0,2 s quieto para que la pieza caiga vertical
        RELEASE_WAIT,    // bomba apagada, esperando que la pieza se despegue
        BOX_TRANSIT,     // modo Box: accel MAX, cruza por encima de la caja
        BOX_APPROACH,    // modo Box: accel MAX, baja hasta 1 cm sobre la celda
        BOX_DESCEND,     // modo Box: accel MIN, apoya la pieza en la celda
        BOX_LIFT,        // modo Box: accel MAX, sale de la caja hacia arriba
        COLLISION_STOP,  // colision detectada: frenado y quieto antes de recalibrar
        ERROR,

        // Modo aprendizaje: el ciclo de clasificacion esta suspendido y el
        // brazo lo maneja el operador desde la interfaz (jog manual) o la
        // reproduccion de una secuencia grabada. Va AL FINAL a proposito:
        // el indice de este enum viaja tal cual en la telemetria y meter un
        // estado en el medio corre la numeracion de todos los siguientes
        // (ver PROTOCOLO.md 3.1). Por eso ERROR ya no es el ultimo.
        TEACH
    };

    // Como se decide a donde va cada pieza. Lo elige el operador desde la
    // interfaz de Python ('C', 'F' o 'A' por Serial).
    enum SortMode : uint8_t
    {
        SORT_BY_COLOR = 0, // tacho 1 rojo, 2 verde, 3 azul
        SORT_BY_SHAPE = 1, // tacho 1 cuadrado, 2 hexagono, 3 circulo
        SORT_BOX      = 2  // llena una caja de 6 con circulos; el resto pasa
    };

    Robot();

    void begin();

    void update();

    // La llama loop() en cada vuelta. Alimenta el contador de vueltas por
    // segundo que sale en la linea de salud de la telemetria.
    void contarVuelta() { telemetria.contarVuelta(); }

    // conservarContexto = true se usa SOLO en la recalibracion posterior a
    // una colision: la cinta nunca se detuvo, asi que las piezas que estaban
    // en la cola siguen teniendo timestamps validos y hay que volver a
    // mirarlas (varias ya no van a ser alcanzables, eso lo filtra
    // planificarPieza). Con false (el arranque y el reset manual) la cola se
    // descarta entera.
    void startHoming(bool conservarContexto = false);

    bool homingFinished() const;

    RobotState getState() const;

    const char *nombreEstado(RobotState s) const;

    bool goToPositionIK(float x, float y, float z,
                        const Motors::MotionLimits &limits = Motors::DEFAULT_LIMITS);

    // Parada de emergencia manual: detiene los 3 motores donde esten y pasa
    // a ERROR. Se dispara con 'R' por el monitor serie. Desde ERROR, otra
    // 'R' rehomea y reinicia el ciclo.
    void emergencyStop();

private:

    // ------------------------------------------------------------------
    //  Pieza detectada por el sistema de vision (Python)
    // ------------------------------------------------------------------
    struct Piece
    {
        float    y;             // cm, Y del centro de la pieza al cruzar la linea
        char     color;         // 'R', 'G' o 'B'
        char     shape;         // 'S', 'H' o 'C'
        uint32_t detectedAt_ms; // millis() en que llego el mensaje
    };

    // Cola circular de piezas pendientes. La consigna es "sin limite", pero
    // en un micro la memoria es finita: con este tamano entran ~32 piezas,
    // muchisimo mas que las que caben fisicamente en el tramo util de la
    // cinta. Si igual se llenara, se descarta la MAS NUEVA y se avisa por
    // Serial (perder la mas vieja seria peor: es la unica que todavia
    // podria llegar a ser alcanzable).
    static const uint8_t QUEUE_CAPACITY = 32;

    Piece   pieceQueue[QUEUE_CAPACITY];
    uint8_t queueHead  = 0;
    uint8_t queueCount = 0;

    bool queuePush(const Piece &p);
    bool queuePop(Piece &out);

    // Motores
    Stepper motor1;
    Stepper motor2;
    Stepper motor3;

    // Finales de carrera
    Endstops endstops;

    // Estado del robot
    RobotState state;

    // Estado de cada eje
    bool axis1Homed;
    bool axis2Homed;
    bool axis3Homed;
    bool homed = false;

    // ------------------------------------------------------------------
    //  Modo de clasificacion
    // ------------------------------------------------------------------
    // MODO CON EL QUE ARRANCA EL ROBOT. Es el unico lugar donde se elige:
    // mientras la vision de Python tenga tomado el puerto serie no se le
    // pueden mandar comandos a mano ('C' / 'F' / 'A'), asi que el modo de
    // arranque se fija aca y se recompila.
    //
    // OJO: el robot NO pregunta nada al encender (no hay contra que
    // comparar todavia), asi que la tapa de la caja tiene que estar puesta
    // ANTES de darle energia si esto queda en SORT_BOX -- y sacada si
    // queda en color o forma.
    //
    // Un cambio de modo que llega a mitad de una maniobra NO se aplica en
    // el momento: se guarda como pendiente y se aplica recien cuando el
    // robot no tiene ninguna pieza en la mano, para no cambiarle el destino
    // a una pieza que ya esta en vuelo.
    // Arranca clasificando POR COLOR: es el modo que no necesita que haya
    // una caja puesta ni que nadie confirme una tapa, o sea el unico que
    // puede empezar a trabajar solo despues de un homing.
    SortMode sortMode        = SORT_BY_COLOR;
    SortMode pendingSortMode = SORT_BY_COLOR;
    bool     sortModePending = false;

    void aplicarModoPendiente();
    const char *nombreModo(SortMode m) const;

    static bool esBox(SortMode m) { return m == SORT_BOX; }
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

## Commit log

2026-03-31 Create pruebamarcos.txt
    Agrego el archivo de prueba para destacar el repositorio en mi perfil.
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2026-05-15 Agrego la carpeta de PlatformIO
    Contiene un código de prueba para controlar un motor NEMA 23 y un código de referencia de otro desarrollo.
2026-05-15 Agrego Driver USB para NodeMCU.
    Los drivers USB son necesarios para cargar código desde PlatformIO a la placa que tiene chip CP210x. Se instalan desde el controlador de dispositivos de Windows.
2026-05-15 Agrego carpeta de electrónica con el Fritzing.
    El fritzing está en su versión "rev3" (sujeto a modificaciones).
    [Diagrama_de_Conexión_KUKO_DELTA_rev3.fzz]
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2026-05-20 Actualización en código
    Módulo conveyor simplificado, elimina errores. Control PWM por AnalogWrite.
    Módulo endstops ahora con código que chequea si los motores llegaron o no individualmente.
    Módulo Pneumatics ahora con código que activa o desactiva la bomba.
    [Conveyor.cpp, Endstops.cpp, Endstops.h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]
2026-06-15 Agrego el código funcionando de los encoders (.ccp y .h). Los incluyo el main.
    En el main agregamos prints para ver que los encoders estén funcionando (no definitivo).
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2026-06-29 Diagrama actualizado con conexiones, colores de cables reales.
    [Diagrama_de_Conexión_KUKO_DELTA_rev4.fzz]
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2026-07-17 Los 3 encoders funcionando de manera analógica.
    Lecturas correctas pero ligeramente fuera de rango. Señal estabilizada mediante capacitores y filtros de media movil y Leaky Integrator.
    [Encoders.cpp, Encoders.h, Endstops.cpp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]
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2026-07-22 Calibracion de ganancia y offset de encoders FINAL.
    Mayor precisión obtenida. Modo analógico.
2026-07-23 Cinematica V1 funcionando.
    Main limpio, cinematica con otro calculo, ejes XY correctamente posicionados.
    [DeltaKinematics.cpp, DeltaKinematics.h, Robot.cpp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]
2026-07-24 Pruebas/mejoras a la cinematica.
    Tratando de solucionar que el error aumenta cuando aumenta la coordenada objetivo.
    [DeltaKinematics.h, Robot.cpp, Robot.h]
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2026-07-28 Prueba de capacidad de movimiento del robot
    Aceleración casi limite para que no vibre. Velocidad todavía hay margen.
    Se puede jugar con micro pasos (20000 actualmente).
2026-07-28 Agrego la primer versión de ConveyorIntercept.
    Código base para coordinar cinta y robot. Teniendo en cuenta:
    Dónde va a estar la pieza depende de CUÁNDO llega el robot.
    CUÁNTO tarda el robot en llegar depende de A DÓNDE tiene que ir.
    Problema de robots industriales reales.
    Es un problema circular — pero se resuelve con iteración de punto fijo: Comienza con una suposición ("el robot tarda X segundos"), se calcula dónde va a estar la pieza en ese momento, se calcula cuánto tardaría realmente el robot en llegar ahí, y se repite hasta que el número deja de cambiar.
    [ConveyorIntercept.cpp]
2026-08-02 Actualización del robot: Definimos velocidad y aceleración.
    Integración de Cloude al VSC: generamos un CLAUDE.md.
    Dejamos el código de la "puesta en escena" del robot por si queremos volver a hacerla. Y despejamos Robot.cpp para seguir avanzando con parámetros del robot.
    Definimos velocidades y aceleraciones definitivamente.
    En Robot.cpp creamos un "probador de v y a" para llegar a esos valores con pruebas reales.
    Eliminamos StepperISR que no utilizábamos. Todas las funciones se controlan con Stepper.
2026-08-02 Avance en funcionamiento dinamico.
    Se reestructuró la cinemática para incluir el offset del efector, se implementó el sistema de colas no bloqueante para las piezas, se gestiona el cambio dinámico de modo (C o F) mediante flags y se d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
2026-08-03 Agrego software de visionIA.
    Programa en Python que también nos va a servir de display.
2026-08-03 Actualización grande de Visión IA.
    Cambio de software de video por uno más eficiente (30FPS).
    Recorte de imagen al tamaño exacto de la cinta.
    Coordenadas en centímetros en vez de píxeles, con referencia al (0,0) del robot.
    Funcionalidad de reconocer el color VERDE y los HEXAGONOS.
    Reacomodamiento del display.
2026-08-04 Comunicación entre cámara y robot funcional!
    La cámara detecta las piezas, le manda al robot y el robot las agarra en movimiento.
    Falta ajustar la manera de agarrar las piezas, las trayectorias que hace.
    Hay veces que choca contra la cinta y se descalibra.
    Cuanto más hacia la derecha y arriba está la pieza, más error tiene.
    [Robot.cpp]
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2026-08-13 Modo alfajores: Nuevo modo funcional V1
    Ordena piezas circulares en una grilla de 2x3 simulando una caja de alfajores.
    Lógica robusta, deja pasar incorrectas, orden de llenado definido.
    Se puede modificar el lugar de cada circulo.
    Trayectoria con aceleraciones controladas.
2026-08-15 Calibración general.
    Ajustes de:
    - Agarre (altura y tiempo de ventosa)
    - Visión (Verde y Azul mejorados)
    - Ajuste de línea de detección (0.5cm)
    - Tensión de cinta (bajarle la tensión, ajuste de Vel)
    - Colisiones (mejor detección, mayor sensibilidad)
    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
2026-08-18 Interfaz V1, pestaña operación al 90%.
    Integración de la interfaz. Ajuste de parámetros.
    La detección de colisiones debe estar afectada, hay que revisar eso, antes andaba mejor. Ahora hay falsos positivos y mediciones erroneas.
2026-08-19 Actualización de interfaz, bugs y comportamiento dinámico.
    Se agregó el contenido de las pestañas de Proceso y Servicio:
    - Lista de ajustes
    - Modificables por slider, flechas y texto.
    Se arreglaron bugs:
    - Encoder 1 leyendo mal (cruce por 0).
    - Problema de rehoming tras perder pasos (no lo hacía).
    - Homing lento (se desaceleraba).
    Cambios en el comportamiento:
    - La bomba de vacío se prende justo antes de bajar, no al llegar (cuando está esperando una pieza).
    - Vel max pasa de 70mil a 12mil (para limitar tramos largos que hacían que el robot pierda pasos).
    [CollisionGuard.cpp, CollisionGuard.h, Encoders.cpp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]
2026-08-19 Implementación del Modo Teach.
    - JOG manual para controlar el robot.
    - Grabación de trayectorias.
    - Reproducción de trayectorias encadenadas.
    - Se creó una pestaña Teach para este modo.
    - Deja de printear el Guard innecesariamente.
2026-08-22 Mejoras en interfaz, modo de coordenadas
    - Modo Teach con coordenadas.
    - Cambios estéticos en la interfaz
    - Ajustes varios
2026-08-22 Movimiento lineal V1 mejorable
    - movL parte la trayectoria en puntos, los encadena "sin frenar".
    - Valida la recta antes de ir (posible imposibilidad articular).
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2026-08-24 Mejoras: Visión, firmware e interfaz.
    - Se recalibró el verde para que se reconozca correctamente (cambiamos el filamento).
    - Se reguló el rango en donde se detectan los hexágonos para no tener confusiones geométricas.
    - Se mejoró la detección de piezas pegadas entre sí.
    - Se cambió el nombre del modo alfajores a modo box.
    - Se optimizó la bajada a la box.
    - Se aumentó la zona de agarre sobre la cinta (Xmax=12).
    - Se dividieron las aceleraciones de agarre de la de la box.
    - Se aumentó la aceleración de agarre para mayor productividad.
    - Se re-ajustaron los valores "de fábrica" de la interfaz.
    - Se resolvió el problema de cartel duplicado en "Caja completa".
    - Se bajó la veloc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
    [CollisionGuard.h, Motors.cpp, Robot.cpp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]
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2026-09-03 Se acomodaron algunas carpetas y archivos del repo.
    [Diagrama_de_Conexión_KUKO_DELTA_rev3.fzz, Diagrama_de_Conexión_KUKO_DELTA_rev4.fzz]
2026-09-04 Se carga la versión final del diagrama de conexión eléctrica.
    - Se actualizaron los componentes y sus conexiones acorde al robot.
    - Se agrega en versión .fzz, .pdf y .png.
    - Se agrupa en la carpeta "Diagrama eléctrico"
    [Diagrama_de_Conexión_KUKO_DELTA.fzz, Diagrama_de_Conexión_KUKO_DELTA_rev4.fzz]
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2026-09-28 Cambios de configuración y diagrama eléctrico final
    - Se actualizan las configuraciones del programa agregando perfiles de iluminación y trayectorias del modo Teach.
    - Se sube el diagrama eléctrico en todos sus formatos y actualizado. Corresponde al conexionado final.
    [Diagrama_de_conexión.fzz]
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2026-09-28 Diagrama de Gantt y Propuesta en su versión final
    - Se suben los Gantt actualizados, en sus versiones finales.
    - Se suben las propuestas actualizadas, en sus versiones finales.
    [Diagrama_de_Gantt_final.xlsx, Diagrama_de_Gantt_inicial.xlsx]
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2026-10-01 Se agregan los videos del funcionamiento a la multimedia
    - Se agregan los videos MP4 de los modos del robot.
    - Se encuentran comprimidos para entrar en los límites de los repositorios de GitHub.
    - Si se desean descargar a máxima calidad, se debe utilizar el link de Google Drive (en el Readme principal).
    - Se actualiza el Readme de la multimedia.
    - Se arregla una ruta desactualizada del Readme principal.
2026-10-01 Se actualiza el informe técnico a la versión con correcciones.
    - Se arregló el encabezado del índice.
    - Se eliminó la revisión de la hoja 44 del informe (45 del documento), "Agregar captura de los motores".
2026-10-01 Se arregla una foto del multimedia que estaba corrompida.
    - La foto 03 del multimedia se corrige por el archivo correspondiente.
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2026-10-02 Se actualiza el modelo de AR en android y PPT
    - Arreglo en el modelo 3D del AR en android que se veía "redondeado".
    - Se agrega el QR de la AR a la presentación en la diapositiva de agradecimientos.
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2026-10-03 Se ajusta el comportamiento durante las colisiones
    - Se ajusta el umbral de ganancia de los encoders en la interfaz (color verde).
    - Se arregla bug de 3 fallas seguidas: Ahora si aparece un cartel y se frena.
    - Se agrega cartel para el fallo de homing.
    [Robot.cpp, estado.py, ui.py]
